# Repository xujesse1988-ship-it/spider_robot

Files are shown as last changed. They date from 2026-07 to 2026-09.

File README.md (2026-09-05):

# Spider · 会爬玻璃的 DIY 六足机器人






<p align="center">
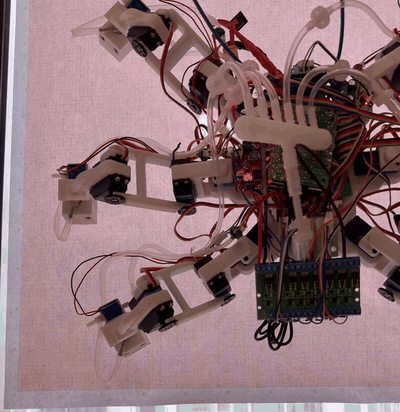
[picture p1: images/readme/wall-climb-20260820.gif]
六足机器人吸在竖直玻璃上原地踏步（2026-08-20）
  
  <br>
  <sub>2026-08-20，竖直玻璃上的原地踏步实验。六只吸盘足，一次抬一条腿，安全绳在画面外。</sub>
</p>

一台 3D 打印的六足机器人：**地上能走，也能吸在竖直玻璃上爬**。18 只几十块钱的舵机、一台隔膜泵、六个十块钱的波纹吸盘，零件总共约两千元。一个 DIY 新手和 AI 结对，从第一次提交到整机上墙用了六周，到现在两个月。

它不是产品，是一张能力证明：用最便宜的零件，把"六条腿上墙"这件事做成了，还顺手发现了一个爬壁机器人的普遍现象并给出了不用传感器的解法（正在写论文）。

> **English summary.** *Spider* is a 3D-printed hexapod that walks on the floor and climbs vertical glass on six suction-cup feet (one normally-closed solenoid valve per foot, one diaphragm pump, no vacuum tank). Brain: Raspberry Pi 5; actuators: 18 × 35 kg·cm hobby servos; parts cost about ¥2,000 (~US$300). Along the way we found that **93% of a climbing step's slip happens in the instant a cup's seal breaks**, and cut three-round slip by **61%** with a sensor-free, purely kinematic "zero-force handover" (paper in preparation, see `docs/PAPER-PLAN.md`). Fully offline voice control. Built in two months by a DIY beginner pairing with an AI coding assistant. MIT licensed; walking platform derived from the open-source [MakeYourPet hexapod](https://github.com/MakeYourPet/hexapod). **Full English translations of every document and report are in [`docs/en/`](docs/en/) and [`html/en/`](html/en/).**

## 它能做什么

| 能力 | 状态 | 说明 |
|---|---|---|
| 竖直玻璃上爬行 | ✅ 2026-08-19 起 | 六足吸盘，每足一只常闭阀，五足支撑一足摆动；不装储气罐，泵直接抽歧管，滞环维持 −60~−75 kPa |
| 停在墙上不掉 | ✅ | 常闭阀断电保持真空，泵间歇工作；掉电不等于掉落 |
| 地面行走 | ✅ | 三角 / 波浪步态，键盘遥控，可调速 |
| 全离线语音 | ✅ 2026-09-02 起 | 喊"小蜘蛛，前进三秒"就走三秒，"停下"立刻停；不联网、不要 API key；声纹锁只听主人，急停谁喊都停 |
| 少往下滑 | ✅ 量化验证 | 零力交接 + 轮转权重：三轮下滑 −61%（n=3，p≈0.001），破裂段 −88% |
| 负重、双墙面、自主上墙 | 🔜 P5 | 见 `docs/ROADMAP.md` |

## 最有意思的一段：每走一步，它都往下滑一点

爬墙跑通之后发现：机器人每换一次脚，整机就往下掉几毫米，三轮下来滑了将近 20 厘米。用手机视频逐帧追踪（NCC 模板匹配 + 阶跃基底分解，188 张核对图入库）之后，答案很干净：

- **93% 的下滑发生在同一个瞬间**：吸盘放气、密封破裂的那一下。
- **原因是腿是软的**：便宜舵机的齿轮系、打印腿、波纹吸盘，整条腿链就是一根弹簧。吸着的时候它承着重力储能，放气瞬间能量一次释放，身体就"弹"下去一格。指令机体位移只有约 42% 被实现，其余都吃进了弹性。
- **解法不用加任何传感器**：放气之前先把这条腿的"力"卸到零。做法纯运动学：给要抬的腿一个离线标定好的位移 δ，其余五条腿按轮转距离加权分摊 −δ，六条腿指令的均值不变，身体不动，腿链里的弹性势能先归还再放气。
- **结果**：三轮下滑 185 mm → 73 mm（−61%），放气破裂段 173 mm → 20 mm（−88%）。这条线正在整理成论文（默认投 RA-L），进度与数字都在 [`docs/PAPER-PLAN.md`](docs/PAPER-PLAN.md)。

想看细节：[`docs/HANDOVER-DESIGN.md`](docs/HANDOVER-DESIGN.md)（设计）、[`html/handover-ab-n3-20260826.html`](html/handover-ab-n3-20260826.html)（n=3 终版报告）、[`html/vent-snap-20260820.html`](html/vent-snap-20260820.html)（现象首次发现）。

## 硬件一览

| 部分 | 用的什么 |
|---|---|
| 步行平台 | [MakeYourPet hexapod](https://github.com/MakeYourPet/hexapod) 3D 打印机身与 coxa/femur（MIT）；小腿换成本项目自制的吸盘一体件 |
| 舵机 | 18 × DS3235 35 kg·cm 数字舵机，¥45~85/只，无任何力矩或位置回读 |
| 舵机板 | Pimoroni Servo2040，跑社区 chica 固件，Pi 经 USB 驱动 |
| 大脑 | Raspberry Pi 5，自研 Python 控制软件 |
| 吸附 | 555 双头隔膜泵 ×1、二位三通常闭电磁阀 ×6、30 mm 2.5 折波纹吸盘 ×6、每足单向阀 + 滤芯、一进六出歧管；无储气罐 |
| 传感 | 六路 XGZP6847A 吸盘压力（ADS1115 读）、母线电压/电流遥测。没有 IMU，没有力传感器，足底开关未启用 |
| 语音 | ReSpeaker Lite USB + 4Ω 3W 喇叭；sherpa-onnx 离线四件套（KWS 唤醒 → Silero VAD → SenseVoice 识别 → Matcha 合成）+ CAM++ 声纹 |
| 供电 | 2S 锂电 7.4 V 直供舵机（继电器切正极）；Pi 独立 5V/5A 降压 |
| 重量 / 成本 | 3.54 kg（2026-09-04 实测，含吸附系统）；零件约 ¥1700~2800，分两批买，见 [`docs/BOM.md`](docs/BOM.md) |

## 软件一览（`software/`）

跑在 Pi 5 上的自研 Python 包，无硬件也能仿真和测试（`--mock`），约 190 项 pytest。

| 模块 | 干什么 |
|---|---|
| `hexapod/kinematics.py` | 单腿 3 自由度正逆运动学 |
| `hexapod/gait.py` | 相位式步态引擎：三角 / 波浪 / 爬墙五足支撑 / 双足摆动 |
| `hexapod/robot.py` | 身体系足端目标 → IK → 18 路脉宽；贴墙姿态偏移 |
| `hexapod/adhesion.py` | 每足吸附状态机（压紧→抽气→吸附→放气）+ 真空回路仿真 |
| `hexapod/driver.py` | Servo2040 chica 串口协议（按固件源码逐字节核实）+ 遥测 |
| `hexapod/voice/` | 唤醒、识别、意图、合成、声纹锁 |
| `scripts/` | `sim_walk` 仿真 → `servo_center` 标定 → `walk_teleop` 键盘走 → `climb_walk` 爬墙 → `voice_teleop` / `voice_climb` 语音 |
| `logs_analysis/` | 手机视频量化管线（`ab_quant.py`）与统计脚本 |

安装、脚本顺序、上电顺序和标定流程见 [`software/README.md`](software/README.md)。

## 两个月时间线

| 日期 | 里程碑 |
|---|---|
| 2026-07-07 | 第一次提交：路线图、BOM、第一批下单 |
| 07-22 | 单腿上墙决策门通过：50 次吸放循环 >95%，挂住 1.5 kg |
| 08-08 | 整机 18 路标定完成，站立实机验证 |
| 08-17 | 每足单向阀装机，一足漏气不再连坐 |
| 08-19 | 整机首次在竖直玻璃上行走（无储气罐） |
| 08-20 | 发现"放气瞬间弹跳下滑"现象；同日实现零力交接 |
| 08-26 | n=3 拉丁方实验：三轮下滑 −61% |
| 08-31 | 论文英文初稿 v0；κ 定律判别实验上墙完成 |
| 09-02 | 语音交互换 ReSpeaker Lite USB，声纹锁上线 |

## 仓库地图

| 目录 | 内容 |
|---|---|
| [`docs/`](docs/) | 路线图、分阶段操作指南、设计论证、论文计划（下表）；英文版在 [`docs/en/`](docs/en/) |
| [`software/`](software/) | Pi 5 控制软件、脚本、测试、视频量化管线 |
| [`hardware/makeyourpet-hexapod/`](hardware/makeyourpet-hexapod/) | 上游步行平台 STL/STEP、接线图（原样收录） |
| [`hardware/climbing-parts/`](hardware/climbing-parts/) | 自制吸盘小腿、门盖、气动舱固定件（[打印说明](hardware/climbing-parts/README.md)） |
| [`tools/`](tools/) | 打印件参数化生成器 |
| [`paper/`](paper/) | 论文 LaTeX 源码（中英）、图、参考文献 |
| [`html/`](html/) | 23 份实验分析与设计图解报告，直接用浏览器打开；英文版在 [`html/en/`](html/en/) |
| [`images/`](images/) | 零件照片、实验视频与 188 张量化核对图 |

### 文档

| 文件 | 内容 |
|---|---|
| [ROADMAP.md](docs/ROADMAP.md) | 分阶段路线图 P0~P5，每阶段验收标准与风险清单 |
| [P0-GUIDE.md](docs/P0-GUIDE.md) · [P1-GUIDE.md](docs/P1-GUIDE.md) · [P2-GUIDE.md](docs/P2-GUIDE.md) | 单腿：下单、打印、装配、真空台架、上墙决策门（含验收数据） |
| [P3-GUIDE.md](docs/P3-GUIDE.md) · [P4-GUIDE.md](docs/P4-GUIDE.md) | 整机：装配、标定、地面行走、气路上机、爬墙步态、启动死机排查 |
| [BOM.md](docs/BOM.md) | 分批采购清单，含淘宝搜索关键词与价格区间 |
| [CLIMBING-DESIGN.md](docs/CLIMBING-DESIGN.md) | 吸附方式选型（为什么不用涵道风扇）、力学预算、气路图、电气架构 |
| [HANDOVER-DESIGN.md](docs/HANDOVER-DESIGN.md) · [HANDOVER-AB-PROTOCOL.md](docs/HANDOVER-AB-PROTOCOL.md) | 零力交接的设计与实机 A/B 实验方案 |
| [DUAL-SWING-DESIGN.md](docs/DUAL-SWING-DESIGN.md) | 双足同时摆动的升级设计 |
| [P4-BAY-DESIGN.md](docs/P4-BAY-DESIGN.md) | 电气与气动舱固定件设计 |
| [VOICE-GUIDE.md](docs/VOICE-GUIDE.md) | 语音交互：硬件接法、离线模型、指令表、抗噪排障 |
| [PAPER-PLAN.md](docs/PAPER-PLAN.md) · [RELATED-WORK.md](docs/RELATED-WORK.md) | 论文总纲、核心数字、文献边界 |
| [weight-log.md](docs/weight-log.md) | 重量记录（爬墙对重量极其敏感） |

## 想自己做一台

开发顺序是按风险排的：**先花几百块用一条腿验证"能上墙"，通过决策门再买整机的舵机**。

1. 读 [`docs/ROADMAP.md`](docs/ROADMAP.md) 的 P0~P2 节。
2. 按 [`docs/BOM.md`](docs/BOM.md) 下第一批单（单腿验证套件，约 ¥600~950）。
3. 等快递时打印一条腿：coxa/femur 用上游 STL（同名多版本取编号最大的），小腿用 `hardware/climbing-parts/left-tibia-suction.stl` + 一件 `suction-foot-door.stl`，装配看上游 YouTube 频道 MakeYourPet。
4. Pi 5 烧 Raspberry Pi OS Lite 64-bit，装 `software/`，先跑 `scripts/sim_walk.py --gif walk.gif` 看步态仿真。
5. 单腿决策门（50 次吸放循环 >95%、撑住 1.5 kg）通过后，再买第二批装整机，按 P3、P4 指南走。

## 安全

- 爬墙测试全程系安全绳、地面铺垫；任何脚本退出都会断舵机电，机器人会趴下，测试时垫高机身。
- 锂电池充电不离人。

## 许可证

本仓库的自研内容（`software/` 控制软件、`docs/` 文档、`tools/` 生成脚本、自制打印件、实验数据与论文源码）以 **MIT 协议**发布，见 [LICENSE](LICENSE)。

第三方内容：

- `hardware/makeyourpet-hexapod/`：MakeYourPet hexapod 原样收录（MIT，Copyright (c) 2022 MakeYourPet.com），许可原文在该目录 `LICENSE`。
- `hardware/climbing-parts/` 中的左右 `tibia-suction*.stl` 派生自上游 `left-tibia.stl`，见 [hardware/climbing-parts/NOTICE.md](hardware/climbing-parts/NOTICE.md)。
- Servo2040 固件 chica（[EddieCarrera/chica-servo2040-simpleDriver](https://github.com/EddieCarrera/chica-servo2040-simpleDriver)，MIT）不包含在本仓库中，`software/hexapod/driver.py` 只实现其串口协议。
- "MakeYourPet" 是上游作者的名称，本项目与其无隶属或背书关系；上游作者的 YouTube 视频等不在 MIT 授权范围内。

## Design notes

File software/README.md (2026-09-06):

# software/ —— 树莓派 5 大脑

Pi 5 通过 USB 连 Servo2040（跑社区 chica 固件），本包实现运动学、步态、驱动协议与吸附控制。
协议已从固件源码逐字节核实（`hexapod/driver.py` 文件头有完整协议说明）。

## 安装

```bash
# 开发机（仿真+测试）
python3 -m venv .venv && .venv/bin/pip install -e ".[sim,dev]"
# 树莓派上（实机）
pip install -e ".[pi]"
```

## 模块

| 文件 | 内容 |
|---|---|
| `hexapod/config.py` | 机器人几何/舵机标定表——默认值全部来自官方 chica-config-2040.txt（连杆 43/80/134mm、通道映射、安装偏角） |
| `hexapod/kinematics.py` | 单腿 3DOF IK/FK（有工作空间检查） |
| `hexapod/gait.py` | 相位式步态引擎：tripod（三角）/ wave（波浪）/ climb（爬墙五足支撑） |
| `hexapod/robot.py` | 身体系足端目标 → 变换 → IK → 18 路脉宽；身体姿态偏移（爬墙贴墙姿态用） |
| `hexapod/driver.py` | Servo2040 chica 协议驱动 + MockDriver；含足底开关/电压/电流读取 |
| `hexapod/adhesion.py` | 吸附状态机（RELEASED→PRESSING→SUCKING→ATTACHED→VENTING）+ 真空回路仿真；`Pi5VacuumIO` 留待 P1 台架按实际接线补全 |
| `hexapod/voice/` | 语音交互（`docs/VOICE-GUIDE.md`）：`intents.py` 识别文本→意图（纯规则）、`keywords.py` 唤醒词→KWS 关键词表、`audio.py` arecord/aplay 录放音、`tts.py` 离线合成+缓存+分句播报、`engine.py` KWS→VAD→SenseVoice 引擎线程、`voiceprint.py` 声纹锁 |

## 脚本（按上手顺序）

```bash
python scripts/sim_walk.py --gif walk.gif        # 0. 无硬件仿真，先看步态对不对
python scripts/servo_center.py                   # 1. 装配标定：全舵机回中，装舵盘
python scripts/stand_up.py                       # 2. 站立测试 + 传感器读数
python scripts/walk_teleop.py                    # 3. 键盘遥控行走 (wasd/qe)；m 键进/出原地踏步（身体不动、手动逐脚：t/g/b=左前中后、y/h/n=右前中后，按一下抬起 70mm 再按踩下，`--march-lift` 改高度；该状态只认这六个键+m+ESC，其余按键忽略；全程六阀通电排气，出踏步时抬着的脚先滑回站位）；装气路后阀策略 --vent auto（默认）：站起/走动时六阀通电排气让吸盘通大气、站着不动断电；on 常通；off 不碰阀=脚被被动真空吸住抬不起（对照，v 键轮换）
python scripts/voice_check.py                    # 4. 语音自检：录 5 秒→回放→识别→TTS（要 ReSpeaker Lite，见 docs/VOICE-GUIDE.md）
python scripts/voice_enroll.py                   # 5. （可选）声纹注册：行走指令只听你，急停谁喊都停；末尾补录"确认/退出"等短词锚点，已有档案用 --append 只补短词
python scripts/voice_teleop.py                   # 6. 语音遥控行走（“小蜘蛛，前进”=一直走喊停为止、“前进三秒”=到点自停、“停下”急停；键盘照旧；阀排气同 walk_teleop）
python scripts/voice_climb.py                    # 7. 爬墙语音壳：climb_walk 原样跑在 pty 里，语音映射成按键注入（急停→空格、“启动”→p、行走→wasdqe、单步/落地→i、“冻结”→f），互锁/黑匣子照旧；退出与取机只认键盘（VOICE-GUIDE §3.9）
```

全部脚本支持 `--mock` 干跑（`voice_*` 还支持 `--wav` 用录音顶替麦克风）。测试：`pytest tests/`（覆盖 IK 往返、步态约束、协议字节、吸附状态机、语音意图/关键词/回声过滤/声纹锁）。

语音一键安装（树莓派）：`bash scripts/voice_setup.sh`，依赖见 `requirements.txt` 语音段。

黑匣子与死机验尸：`climb_walk`/`body_lean`/`walk_teleop`/`voice_teleop` 每跑一次落一份 `logs/<tag>_时间.log`（tag=climb/lean/walk/voice；事件+遥测，`hexapod/runlog.py`）。09-02 起启动段逐步落盘（每路阀线圈通电前、舵机继电器合闸前后母线电压），并由 `hexapod/powerlog.py` 后台线程每 0.1s 记一行 Pi 5 的 5V 输入电压与欠压标志（`TLM 电源`，需 `vcgencmd`，用户在 video 组）。启动死机（灯绿→红、SSH 失联）排查：先 `bash scripts/pi_forensics.sh setup`（内核日志持久化，一次即可）→ 复现 → 重新上电 → `bash scripts/pi_forensics.sh check`；`check` 里的 `power_reset` 两次死机后都是 2，但 09-06 对照发现正常关机后也读 2，本机无区分力，仅作记录；死后红灯常亮本身就是 PMIC 断电的证据。详见 docs/P4-GUIDE.md 常见问题。

## 上电顺序（重要）

1. Pi 5 用独立 5V/5A 降压模块供电，舵机 7.4V 经继电器（Pi GPIO17 控制，08-15 定案，原 Servo2040 A0/GPIO26）供电。
2. 软件流程：先 `set_all_pulses_us` 发好目标脉宽 → 再 `enable(True)`。固件保证舵机使能瞬间直接到设定位，不乱跳。`enable(True)` 内部拆两步：先合继电器（舵机带电不出力）→ 0.4s → 固件使能（同刻出力）；09-03 实机定案启动死机扳机就是合闸瞬间（5V 输入空载仅 4.89V 余量极薄），拆开后峰值分开、黑匣子能分清是哪一记。
3. 任何脚本退出/异常都会 `enable(False)` 断舵机电——机器人会趴下，测试时垫高机身。进程被杀时 lgpio 释放 GPIO17，继电器同样自动断电。

## 标定流程（装配后必做）

1. `servo_center.py` 让全部舵机回中，按官方视频角度装舵盘；
2. 每个关节手动摆到 -45°/+45°，记录脉宽，填入 `config.py` 的 `us_m45/us_p45`；
3. 方向相反的舵机改 `sign=-1`；零位偏差微调 `attach_deg`；
4. 换上吸盘足模块后重新量 `tibia_len`（约 +45mm）。

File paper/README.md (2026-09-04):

# RA-L 论文草稿(T6)

状态:**英文全文初稿 v0(2026-08-31)+ 09-01 读者视角修订**(面向没参与造机器人
的读者:腿命名/术语/隐喻全部落地,图 1 示意图已画,摘要删去"慢放气"跳跃句;
中文版同步)——全部章节成文、核心数字已嵌入,待补图/待办见下。总纲 `docs/PAPER-PLAN.md`;本目录只放论文本身。

## 文件

- `main.tex` — 正文(IEEEtran journal 模式,RA-L 口径;红色 `\TODO{}` 为待办标记)
- `main_zh.tex` / `main_zh.pdf` — **中文对照版**(供内部审阅/交流,非投稿稿;
  与 08-31 英文稿逐节对应,数字/公式/引文/图表一致)。⚠ 投稿以英文为准,
  改英文后中文不自动同步——大改后要么重译要么在中文版头注明滞后。
  编译需 XeTeX+中文字体:本机 Noto Serif/Sans CJK SC 已放 `~/.fonts`
  (仓库不含字体,新机器 fc-list 查无则从 notofonts/noto-cjk 下载);
  Overleaf 上传时选 XeLaTeX 编译器
- `refs.bib` — 45 条引文(源自 `docs/RELATED-WORK.md` 判级表;
  条目内 `TODO(verify)` = 投稿前须人工核全文的字段,总清单在 RELATED-WORK §7)
- `figures/` — 插图(生成脚本与来源见各文件头/下表;`make_fig1.py` 生成图 1
  示意图 (a)(b)(c),纯几何不依赖实验数据;`make_figs.py` 生成图 2–5)
- `references/` — 参考文献 PDF,**文件名=refs.bib 引用键**(现有
  nadan2024loris.pdf=LORIS ICRA 2024,CMU 作者公开版——写作范本兼
  贡献③划界近邻;写作范本首选另见 kim2008smooth=Stickybot T-RO 2008,
  叙事弧同构:同一个敌人"脱附瞬态"、同款"脱开时刻本来就没力"哲学)

## 编译

开发机没装 LaTeX。两条路:

1. **Overleaf(推荐)**:上传 `main.tex` + `refs.bib` + `figures/`,
   编译器选 pdfLaTeX,IEEEtran 类 Overleaf 自带;
2. 本机装 `texlive-publishers`(含 IEEEtran)后:
   `pdflatex main && bibtex main && pdflatex main && pdflatex main`;
3. **本机实际在用的路**:`~/.local/bin/tectonic main.tex`(单命令,自动多遍+bibtex;
   中文版 `tectonic main_zh.tex`,XeTeX 自动选中)。

## 数字溯源(写作时改数必查源)

| 论文位置 | 数字 | 来源 |
|---|---|---|
| 摘要/主表 Table I | −43%/−61%,−82%/−88%,p=0.0013/0.00092/0.0022 | html/handover-ab-n3-20260826.html §1 |
| 头条口径 | 93%(n=3 A 组 vent 段 172.9/185.5);83%=08-20 首次发现口径 | 同上 + html/vent-snap-20260820.html(口径差异=分段窗定义,正文已注) |
| 破裂剖面 | 0.4s 泄压 <0.15mm;33~67ms 完成;正文与图 2b 同一事件:L1 过冲 26.7→21.5(0825/A 重复#1,`ab_quant --zoom`);08-20 首次发现事件为 23.8→21.5(正文不再引用,避免两套数字) | html/vent-snap-20260820.html §4;PAPER-PLAN T3 |
| δ 标定 | 斜率 −0.57~−0.13;δ* 28~42;表 31/33/29/22/22/24;66→50→39mm;δ*/b(0)=1/s 逐腿 **1.7(L1)~8(R2)**(旧稿写 5~8 是等刚度粗算,09-01 已改) | html/handover-delta-calib-20260824.html §3 |
| 传递比 | 42.2±3.0%(9 标记/3 天/3 机位) | n=3 报告发现 2 |
| 模型拟合 | RMSE 0.85/CV 0.99;两路 k̂ r=0.938;B 60.2=6.7+55.5;C 39.7=7.7+30.0 | html/stiffness-fit-20260826.html |
| κ 定律 | Δb=κ·δ(1+0.20(r−1));κ_B 0.0988/κ_C 0.0550/κ_31 0.0529;权重压 44% | html/dprime-20260831.html(M10 AICc 0.0 vs M8 17.8;216 点) |
| D′ 配对 | D′−C 交接段 −2.9±2.1(p=0.14);总 −1.7±0.7;落点比例 0.21;合并段 −3.0±3.1 | 同上 §1-2 |
| vent 窗定义 | 起点=A 组阀开前 1s / B、C 组阀开时刻(交接段终点);终点=released 事件(盘压回到 ≥−5kPa,俗称"盘压归零")后 +0.4s;两端锚不同事件、非"归零 ±" | software/logs_analysis/ab_quant.py:575-595(09-01 已核,论文已按此改写) |
| 联合 k̂ | L1 0.265/R1 0.227/L3 0.137/R2 0.133/R3 0.125/L2 0.112;γ=0.11 | 同上 §3 |
| 系统参数 | 吸附 ≤−30kPa 持续 0.2s;泵滞环 −60/−75(**作用于最浅已吸附盘压**,任一盘抽气中泵常开);抬腿门槛 −50kPa;**全部 15 组实验 --no-tank、单泵直抽歧管**(储气罐从未装机);连杆 43/**81**/123.7;抬腿=名义面上 15mm(指令行程 33=press 18+15) | software/hexapod/adhesion.py, config.py, body_lean.py,日志 argv(09-01 已核) |

## 待办(投稿前;`main.tex` 内红字与此同步)

1. **作者/单位/邮箱/资助**(main.tex 头部)。
2. ~~**整机称重**~~ ✅ 09-04 实测 3537g:Sec III-A 中英已改 $3.54$ kg、\TODO 已删;讨论段 "sub-3 kg climbers" 随之改 "few-kilogram climbers"(中文"几公斤级"),因为本机已不在 3kg 以下。
3. **图**:Fig.1 示意图 (a)(b)(c) 已由 `make_fig1.py` 生成,**真机照片 (d) 待拍**;Fig.2 阶梯轨迹+破裂剖面
   (T3,`ab_quant --zoom`);Fig.3 弹跳-δ 线性;Fig.4 分解瀑布+逐腿弹跳;
   Fig.5 D′ 对齐剖面。figures/ 里已生成的见文件头注释,其余 `\TODO`。
4. ~~vent 窗定义核对~~ 09-01 已从 ab_quant 源码确认并改写(见溯源表)。
5. **T4a 挂重**(绝对 k+蠕变率直测)与 **T4b 净前进率 demo**(26%→X%)
   结果出来后并入 Sec VII(讨论已留钩子);26% 基线数字当前来自 08-19。
6. **投稿视频**:A vs C 并排 + 破裂慢放(MOV 原片冻结在本机,协议见 PAPER-PLAN T6)。
7. **开源数据包**:日志/traj/report/188 张核对图/管线脚本打包,定托管处与许可证。
8. **refs.bib 逐条核全文**(`TODO(verify)` 字段 + RELATED-WORK §7 清单:
   Kumar&Waldron 1990 措辞、FTFOF 开/闭环细节、Ota 2006 正文、CNKI 硕博)。
9. **篇幅**:RA-L 8 页含引文;当前英文稿 10 页(09-01 加图 1 + 术语解释后从 9 页涨到 10),定稿时砍
   (候选:Related Work 六段压四段、P1-P4 合并表述、偏差清单压缩)。
10. 术语统一自查:vent-snap ratchet / zero-force handover / handover segment /
    rupture segment / transfer ratio / per-mm transfer loss(κ)。
    09-01 已统一:"laid/laying"→transfer(ed);"up/down-slope"→up/down the wall;
    "winding"→loading;"gait engine"→gait controller;M10/M8→H2/H1;
    定义处:leg names(III-A)、round/rotation(III-C)、body lean(III-B)、
    discovery run(I)、rupture-segment slip(III-B)、leak-rescue(V-D)。
11. **靶标交叉验证跑 + 核对图整理(09-01 新增,详见 PAPER-PLAN T4d)**:
    贴 Ø20 同心圆靶标(`html/tracking-targets-printable.html`)跑一组原地
    基线,同一视频板模板 vs 靶标两种追踪比对,III-B 改写为"两种追踪一致到
    X mm";此后所有上墙视频一律贴靶标。**不重做 n=3/D′**(理由见 T4d)。
    在此之前:III-B 那句"人工对 188 张核对图核查"要改为不带张数、不称
    人工(操作者确认过的只有皮尺 4 帧);`images/ab-verify-202608/` 只有
    board_scale×9 + locate×15 + 皮尺 12 张是自解释核对图,开源包只放这
    36 张 + 索引 README,其余 ~150 张读角过程图挪子目录。

## 09-01 事实核查修正清单(改回去就是错的,动这些句子前先看源)

三路核查(代码/日志、n=3+标定报告、拟合+D′ 报告)对全文事实句逐条比对后改掉的口径:
- 传感器:机器人**有**六路吸盘压力传感器+母线电压/电流遥测(无 IMU、足底开关未接、舵机无回读)。
  只能写"交接不用任何传感反馈/不新增传感/无力传感",不能写"零传感器/no pressure feedback"。
- 气路:无储气罐、单泵直抽歧管;阀断电=吸盘↔歧管(失电安全),通电=通大气;单向阀在歧管—阀之间。
- 协议:n=3 九组**没有**内建 60s 静置(人工 21~58s;60s 内建 08-26 才加,只对 D′ 六组有效);
  腿间节拍=≥10s 且泵停 ≥2s,实际全由 10s 下限决定;首场电压 7.88V(非 ≥7.9);
  机位在 #1 A→B(~128px)、#2 C→A(数十 px)组间动过,"场内未动"是错的;组内漂移 ≤4.8px。
- 现象:软腿 vent 弹跳 L2 3.5/R2 6.1(5.8/5.9 是全周期列,HANDOVER-DESIGN §1 混列);脚回弹 9~15 为下限;
  静置段 2.4~4.7mm/组(不是"零");"131 vs 131.3"是分段和核对,其比例本就由该读数标定,不是独立验证。
- 模型:e/b=(K−k)/k 逐腿 1.7~8(非 5~8);"弹跳 21mm 饱和低于线性预测"是 08-20 推测且被 24~28 实测推翻,
  改为"硬腿 20~27 平台+模型高估前进损失 ⇒ 归因扭矩饱和(假说)";P2 首抬 n=3 基线 2.5~4.3 非 ≈0;
  P3 4.6 用的是斜率 k̂、RMSE 0.85 是 54 单元含共模项;P4 "全给一条 0%/非单调"不可复现已删,+30% 是温和档反向;
  B→C 跨指标 −30~−36%(非 −31~−33)。
- 方法:首轮指令伪迹按部署表仿真 ≈14mm(B)/20mm(C)(旧 ≤5mm 来自旧表);δ 表**未**在权重下重标,B/C 同一张表;
  "首版表 74→50"无此实验已删;代码 ≈150 行(含注释 270)。
- 结果:R1 上弹实测两次 ≈−0.9mm(B 组),−1~−3 是协议预期值;交接段占比 B 56~58%/C 47~62%;
  R1 交接段不逐轮增长;其余四腿 0~2mm;传递比"2 天 3 场 5 机位";相对效应重复间差 ≤5 点(非 3)。
- 拟合/D′:k̂ 与 c0 退化,只报排序/比值可靠(c0=1.15);共模占比 B 92%/C 76~84%(非"九成");
  L1 残余系数按自报 k̂ 为 0.038≈1.4mm/次(0.019 是旧拟合);观测数据上 H1/H2 不可分(ΔAICc≈2 略偏 H2),
  "H1 险胜"是错的;D′−C 差"主要是窗口归因"只对 1/3 配对成立;偏差(vi)是 D′ 两组、挪 4~5mm/组。
- 上游文档 docs/HANDOVER-DESIGN.md §1/§5 仍留着"5~8 倍""L2 5.8"等旧口径,引用前以本表为准。
- 语气:09-01 按用户要求去修辞化(中英同步)——删掉"纳税/这笔税""住进指令流""下一个要拉的杠杆""头条""教科书式""互相较劲""明码标价""翻案""白捡""最凶""口味""恰恰…最付不起"等隐喻和戏剧化强调,讨论节两个反问式小标题改为陈述式;写新句子沿用平实学术表述,不要再往回加。

## 措辞红线(T5 定界,动 Related Work/贡献段前必读)

- ❌ 不写"首次提出脱附前卸载"(Stickybot 专利 US7762362B2 + LORIS Unload 步在先);
  ✅ 只主张:位移域换算 + 零传感器纯开环 + 破裂段滑移量化验证。
- FTFOF 的 −82% 是振动(m/s²),与我们 −82%(mm)量纲不同——正文已点破,勿删。
- 发现 2(42% 传递比)写"平台特性表征",不写"新物理"。
- 所有"首次"均带 "to the best of our knowledge"(CNKI 墙内是唯一未彻底排除的暗区)。

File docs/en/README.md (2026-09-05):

# English versions of the project documents

Every file here is a full English translation of the same-named file in [`docs/`](../). The Chinese originals are the maintained source; if the two differ, the Chinese version wins. Links between documents stay inside this directory; references to HTML reports point to their English versions in [`html/en/`](../../html/en/). The data files (`docs/data/`) are shared and not duplicated.

| Document | What it covers |
|---|---|
| [ROADMAP.md](ROADMAP.md) | Staged roadmap P0–P5 with acceptance criteria and risk list per stage |
| [P0-GUIDE.md](P0-GUIDE.md) · [P1-GUIDE.md](P1-GUIDE.md) · [P2-GUIDE.md](P2-GUIDE.md) | Single leg: ordering, printing, assembly, vacuum test rig, the wall decision gate (with acceptance data) |
| [P3-GUIDE.md](P3-GUIDE.md) · [P4-GUIDE.md](P4-GUIDE.md) | Whole robot: assembly, calibration, floor walking, pneumatics on the robot, climbing gait, startup-crash troubleshooting |
| [BOM.md](BOM.md) | Purchase list in batches, with Taobao search keywords and price ranges |
| [CLIMBING-DESIGN.md](CLIMBING-DESIGN.md) | Adhesion method selection (why not ducted fans), force budget, pneumatic circuit, electrical architecture |
| [HANDOVER-DESIGN.md](HANDOVER-DESIGN.md) · [HANDOVER-AB-PROTOCOL.md](HANDOVER-AB-PROTOCOL.md) | Design of the zero-force handover and the real-machine A/B experiment protocol |
| [DUAL-SWING-DESIGN.md](DUAL-SWING-DESIGN.md) | Upgrade design for swinging two legs at once |
| [P4-BAY-DESIGN.md](P4-BAY-DESIGN.md) | Mounting parts for the electrical and pneumatic bay |
| [VOICE-GUIDE.md](VOICE-GUIDE.md) | Voice interaction: hardware, offline models, command table, noise troubleshooting |
| [PAPER-PLAN.md](PAPER-PLAN.md) · [RELATED-WORK.md](RELATED-WORK.md) | Paper master plan, core numbers, literature boundary |
| [LEG-GEOMETRY-OPEN.md](LEG-GEOMETRY-OPEN.md) · [L3-DISPUTE-OPEN.md](L3-DISPUTE-OPEN.md) | Leg-geometry investigation record and the resolved tibia-length dispute |
| [weight-log.md](weight-log.md) | Weight log (climbing is extremely sensitive to weight) |

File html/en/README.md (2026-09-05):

# English versions of the HTML reports

Every file here is a full English translation of the same-named file in [`html/`](../). The Chinese originals are the maintained source; if the two differ, the Chinese version wins. Each page is self-contained (only Google Fonts are loaded from the network) and opens directly in a browser.

## Experiment reports (in date order)

| File | What it is |
|---|---|
| [press-lurch-20260819.html](press-lurch-20260819.html) | First real climb on the glass door: why a leg gets "dragged down" before lifting (press reaction bending the leg chains, not cup slip) |
| [vent-snap-20260820.html](vent-snap-20260820.html) | Stepping-in-place experiment quantified: 83% of the slip happens at the instant the vented seal ruptures; the vent-snap ratchet and the zero-force handover idea |
| [handover-delta-calib-20260824.html](handover-delta-calib-20260824.html) | δ calibration in three runs (δ = 0/12/24): bounce is linear in δ, extrapolated δ* = 28–42 mm per leg; bounce ≠ stored energy |
| [handover-ab-20260825.html](handover-ab-20260825.html) | Three-run A/B/C on the wall (baseline / handover / handover + weights): −42% and −61% three-round slip, replicate #1 |
| [handover-ab-n3-20260826.html](handover-ab-n3-20260826.html) | n=3 Latin-square main results: −43% / −61% total slip, −82% / −88% at the rupture instant, paired tests, deviation log |
| [stiffness-fit-20260826.html](stiffness-fit-20260826.html) | Parallel-spring model fit of the handover segment: ~90% of the residual is common-mode sinking, not stiffness inequality; gate decision on the stiffness-aware share |
| [dprime-20260831.html](dprime-20260831.html) | D′ discrimination experiment: handover-segment sinking is proportional to the amount apportioned, not to time (the κ law); weights cut κ by 44% |
| [pi-crash-ground-loop-20260904.html](pi-crash-ground-loop-20260904.html) | Case file: Raspberry Pi 5 dying at servo-relay closure, traced to a charging pulse entering through the USB ground loop |

## Design drawings and wiring (P2–P4)

| File | What it is |
|---|---|
| [fkp-glass-poses.html](fkp-glass-poses.html) | P2: the FKP leg triangle relative to the glass in the lift-off and press poses |
| [p2-rig-diagram.html](p2-rig-diagram.html) | P2: single-leg wall test rig geometry (side view, to scale) |
| [coxa-pedestal-mount.html](coxa-pedestal-mount.html) | P2: printed coxa pedestal / one-piece carriage for the rig, with the 2026-07-19 measured corrections |
| [theta-measure-diagram.html](theta-measure-diagram.html) | Single-leg calibration: which angle θ / α / γ is and how to measure it |
| [tibia-three-view.html](tibia-three-view.html) | Tibia printed part in three views: knee axis = servo output shaft, l3 = 123.7 mm (dispute closed) |
| [p4-system-diagram.html](p4-system-diagram.html) | P4: whole-robot electrical + pneumatic connection topology, relay wiring, valve state semantics |
| [p4-pi-wiring.html](p4-pi-wiring.html) | P4: Pi 5 pin-level wiring (40-pin header, USB, power routes) |
| [p4-divider-board.html](p4-divider-board.html) | P4: 7-channel divider board build drawings (schematic, perfboard layout, checklist) |
| [p4-pneumatic-electrical.html](p4-pneumatic-electrical.html) | P4: terminal-level wiring of the pneumatic subsystem (dual 12 V rails, MOSFET board, grounds, current budget) |
| [p4-bay-v1-assembly.html](p4-bay-v1-assembly.html) | P4: interactive 3D assembly view of the V1 equipment bay and whole robot |
| [tracking-targets-printable.html](tracking-targets-printable.html) | A4 print page of vision tracking targets (1:1) for the video pipeline |

## Explainers

| File | What it is |
|---|---|
| [gait-to-servo.html](gait-to-servo.html) | From a walk command to 18 servos: the full climb_walk chain (phase clock, IK, calibration, serial packet) |
| [servo-primer-20260821.html](servo-primer-20260821.html) | Servo primer: what is inside, how it reads an angle, how it misbehaves under load, what to buy |
| [knowledge-map-20260821.html](knowledge-map-20260821.html) | Knowledge map: the thirteen areas this project needed, what to learn first, six lessons not in the books |
| [dev-timeline-20260821.html](dev-timeline-20260821.html) | Development timeline 2026-07-21 to 08-21, compiled from the chat sessions |

The English pages were produced by extracting every Chinese text segment from the original (text nodes, attributes, JavaScript strings, source comments) and injecting translations back without touching markup, CSS, SVG geometry or embedded images. Some SVG labels are longer in English than in Chinese and may sit closer to neighboring elements than in the original.

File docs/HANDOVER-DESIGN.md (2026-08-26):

# vent 前零力交接（zero-force handover）· 实现设计

状态：**已实现**（2026-08-20 定稿并同日实现：`hexapod/climb.py` update() 4.7 步
+ `LegConfig.handover_mm` + 两脚本 `--handover`；测试 §7 全部 8 项 + mock 冒烟
通过。实现时的设计外补充：`scripts/sim_walk.py` 的 CLIMB_COLOR 也按相位取色，
已补 HANDOVER 键——与 §3.2 PHASE_CH 同族的 KeyError 隐患，设计漏列。
**待办：§9.3 实机 A/B 验收**——实验方案与量化工具已备好：
`docs/HANDOVER-AB-PROTOCOL.md` + `software/logs_analysis/ab_quant.py`）。
2026-08-24 多摆泛化（docs/DUAL-SWING-DESIGN.md，双足爬行）：`_ho_left`
改按腿存（两交接可重叠）、分摊改每 tick 按当前 STANCE 集合现算（单足工况
与旧定格逐位一致；权重表仍在放行时定格）、δ=0 也统一先进 HANDOVER（同拍
直落 VENT，拍间不可观测）、放气加"窗头序队列+VENT_STAGGER_S 错峰+门槛
复检"三关——本文 §3.4/§3.5 的"一次一腿、不需要按腿存"描述仅存档，现行
实现见 climb.py 4.7 步。同日 v1.1：权重（§5 v1.5）双足解禁——单足实测
权重对下滑改善明显后，份额改"按轮转距离取值+当前支撑集就地归一"
（_share_now，每 tick 现算；单足恒 5 支撑=与定格表逐位一致），档位按
口径分家：双足推荐 1,1,1,0,0、单足激进档勿照搬（DUAL-SWING-DESIGN
§3.5/附录 C 模型）。
实测依据：`html/vent-snap-20260820.html`（08-20 原地踏步实验量化报告）、
`software/logs_analysis/lean_20260820_102117.log`、`images/lean_20260820.mp4`。

---

## 1. 要解决的问题（一段话）

零指令原地逐腿抬落，机器人每轮沿墙下滑 57→74mm；逐帧量化显示 **83% 的下滑
发生在放气密封破裂的一瞬间**（阀开后 0.4s 泄压期身体位移 <0.15mm，破裂后
<100ms 内一步坠到位，带过冲振铃）——被抬腿自吸附以来储存的弹性势能
（身体每下沉 1mm，该腿被绕紧 1mm）在脱吸瞬间释放，身体坠到其余五腿的新增
变形接住为止，随后被下一次吸附锁死成棘轮。press 落地只占 4%（vent-first
时序下 press-lurch 已退居次要）。整机电流 0.73→~1.9A 逐周期爬升不回落，
是腿间内应力累积的电学证据。**慢放气已被数据否决**：力的释放不随泄压渐进，
全部压缩在唇口脱开一瞬——治法只能是让脱开时刻这条腿本来就不带力。

单次弹跳按腿（第二轮，mm）：L1 20.9 / R1 19.2 / L3 13.5 / R3 11.8 /
R2 5.9 / L2 5.8。前腿（上方腿，剥离力矩集中）最大。单腿弹跳封顶 ~21mm
（舵机扭矩饱和限制单腿储能），这解释了爬行仍能净前进 26% 而非倒退。

## 2. 原理

**吸住的脚不能滑 ⇒ 改指令 = 改力，不改位。** 这是整个方案的物理基础，与
现有 VENT 段"贴面随支撑场平移"完全同一性质（引擎已有先例，update() 第 4 步）。

一维弹簧账（每腿一根弹簧 k，y_i = 锚点 − 指令 = 该腿"暗示"的身体位置，
X = mean(y_attached) − mg/(n·k)）：抬腿 j 无跳变的充要条件是 **f_j = 0**，
即 y_j = mean(其余) − mg/5k。做法：**把被抬腿的足端指令沿"上坡"方向还 δ
（卸载自己），同时其余五条支撑腿的指令各沿"下坡"方向多走 δ/5（接住载荷）**
——六腿 y 的均值不变 ⇒ 身体纹丝不动；y_j 单独降 δ ⇒ f_j 清零。随后放气，
密封破裂时无能量可释放。1-D 模型验证（附录 A）：基线净前进 25.8%（与实测
26% 咬合）→ 零力交接后 100%；原地踏步 −35.6mm/周期 → 0。

三个工程性质：

- **其余腿承担的力不超过抬腿后本来就要承担的量**——交接只是把载荷移交提前、
  并做成无损，没有新的最坏工况；
- 指令几何自洽有界：某腿在一个周期里作为支撑腿吃 5 次 δ/5（共 −δ 下坡），
  轮到自己抬时先 +δ 卸载正好抵回站位附近，落点又是站位——指令不发散，
  单腿最大额外外摆 ≈ δ（工作空间账见 §4.7）；
  ⚠ **"均值不变 ⇒ 身体纹丝不动"在逐腿 δ 表下只近似成立**（审核实测）：
  落地把被抬腿放回默认站位=丢弃其累计交接偏移，"正好抵回"只在均匀表下
  精确。逐腿表（L1 17…L2 5）下，一条腿支撑期吃进 ≈ mean(其余 δ)、轮到
  自己归还的却是 δ_i，残差在落地瞬间被复位吞掉——六腿指令均值每次落地
  跳一步（L1 落地 ≈8mm 上坡、L2 ≈6.4mm 下坡）。真机引擎按协议抬腿序
  实测：首轮累计 ~4.8mm 上坡指令伪迹（行走时峰值 10.7mm）、轮内 ±1.3mm
  摆动（均匀表 0.53mm）；**稳态每轮漂移仍为 0**。判读纪律见 A/B 协议
  §1 判据 4 注与 §6 首轮分支；
- 方向沿 `_down`（下坡方向，随积分航向旋转，与 sag_comp 同一套）：本实验
  横向漂移仅 7.6mm/131mm，纵向单轴假设成立。

## 3. 机构设计

### 3.1 配置

- `LegConfig.handover_mm: float = 0.0`——逐腿交接量 δ（0=关，默认关；与
  `press_delta_mm` 同为逐腿字段）。放 LegConfig 而不是 RobotConfig：实测
  逐腿差 4 倍（L1 17 vs R2 5），全局一个值没法用。
- `RobotConfig.handover_rate_mms: float = 10.0`——交接铺设速率（08-26 起
  参数化，单源在 config；`climb.HANDOVER_SPEED_MMS` 降级为默认别名供测试/
  文案时长账）。默认 10 与 LEAN_SPEED_MMS 同量级（吸住的脚改指令要慢，给
  载荷重分配留准静态时间），δ=17 时交接段 ~1.7s、δ 表 22~33 时 ~2.7-3.8s。
  引擎 `__init__` 守卫 0<rate≤50(nan/inf 拒)——CLI 之外直设 config 的路径
  也拦(与权重同教训)。**D′ 判别实验=20**:T1 拟合(html/stiffness-fit-
  20260826.html)发现交接段 ~九成是"共模下沉≈蠕变率×窗时长",而窗时长
  ≈0.5+δ/rate 与 δ 完全共线,提速是"时间蠕变 vs 逐 mm 损耗"的唯一离线
  判别(协议 §9)。

### 3.2 新相位

`LegPhase.HANDOVER = "handover"`，插在窗头决策与 VENT 之间：

```
STANCE →(窗头决策放行)→ HANDOVER →(δ 铺完, request_release)→ VENT → LIFT → …
```

⚠ `runlog.PHASE_CH` 必须加 `"handover": "Z"`（零力）——status_line 和
ClimbWatch 遥测都查这张表，漏加 = KeyError 炸主环/黑匣子。ClimbWatch 的
相位跳变日志（`相位 X stance→handover`）走 `.value` 通用路径，自动生效。

### 3.3 窗头决策改动（update() 第 2 步 else 分支）

现有该分支做的事**全部保留原位**：`landing` 计算、轮次推进（step_leg）、
`_swung_since_go` 记账、sag_comp 装填、`step_pending→step_active`、
`_slot_active = True`。唯一改动是收尾动作分叉：

```python
if self.cfg.leg(cur).handover_mm > 0.0:
    self._ho_left = self.cfg.leg(cur).handover_mm
    self.phase_of[cur] = LegPhase.HANDOVER      # 先交接，不放气
else:
    self.ctl.request_release(LEG_NAMES.index(cur))
    self.phase_of[cur] = LegPhase.VENT          # 现行为，一字不动
```

`request_release` **推迟到交接完成**才调用——交接期间吸盘必须保持密封吸附
（ATTACHED 控制环照跑，互锁/漏气监护对它照常成立）。

### 3.4 交接运动（update() 新 4.7 步，紧跟 4.6 倾身之后）

与 4.5（下滑补偿）/4.6（倾身）同一类"直接改足端目标"的全局步：

```python
# 4.7 零力交接：被抬腿沿上坡还 δ（卸载），其余支撑腿各沿下坡 δ/n（接载），
# 均值不变=身体指令不动；按真实时间匀速铺（载荷重分配是准静态过程），
# 漏气挽救期暂停（漏着的盘摩擦余量低，不该被推）。铺完才放气进 VENT。
if (not leak_pause and self._slot_active and self._slot_leg is not None
        and self.phase_of[self._slot_leg] == LegPhase.HANDOVER):
    cur = self._slot_leg
    step = min(self._ho_left, HANDOVER_SPEED_MMS * dt)
    self._ho_left -= step
    dx, dy = self._down
    sup = [n for n in LEG_NAMES if self.phase_of[n] == LegPhase.STANCE]
    self.foot[cur][0] -= dx * step          # 反下坡 = 上坡 = 卸载方向
    self.foot[cur][1] -= dy * step
    for n in sup:                           # 用实际支撑数而不是写死 5
        self.foot[n][0] += dx * step / len(sup)
        self.foot[n][1] += dy * step / len(sup)
    if self._ho_left <= _EPS:
        self.ctl.request_release(LEG_NAMES.index(cur))
        self.phase_of[cur] = LegPhase.VENT
```

`_step_swing` 加一个 `elif ph == LegPhase.HANDOVER: pass` 分支（运动在 4.7
驱动；`_seg_t` 照常计时备诊断）。不需要独立超时监护：速率固定必然铺完，
唯一能拖住它的是 leak_pause，而漏气自己有 `leak_rescue_s` 冻结兜底。

### 3.5 引擎新状态

`__init__` 加 `self._ho_left = 0.0`。一次一腿的窗序保证同时至多一个交接
在途，不需要按腿存。

## 4. 与现有机制的相互作用（逐条，全是坑）

1. **⚠ 支撑场跟随（最大的坑）**：update() 第 4 步现在只让
   `(STANCE, VENT)` 的脚随支撑场平移并保持压入深度。HANDOVER 期间脚仍然
   吸在墙上，行走模式下身体在动，**必须一并跟随**，否则该脚在墙面系被拖着
   划、蹭移还密封着的唇口。改为 `(STANCE, VENT, HANDOVER)`，z 保持
   压入深度的那行同样覆盖 HANDOVER。交接位移（4.7）叠加在场平移之上，
   与 sag_comp 叠加口径相同。
2. **相位钟**：HANDOVER 非 STANCE，第 3 步走 `adv = min(dt, 窗剩余)` 分支
   ——爬行模式窗头 0.6s 用不完 1.7s 交接，钟停在窗尾等它，周期自然拉宽
   （与现有"钟停等吸附事件"同语义，不需要新代码）。原地抬起（零速）钟本来
   就空转，无影响。
3. **sag_comp（4.5）**：注入条件是 slot 腿在 LIFT/TRANSFER，交接期间不注入,
   天然互斥。**交接生效后建议把 sag_comp 归零停用**——它是"坠后追补"的
   治标层，两者同开会双份推挤支撑系白吃工作空间（A/B 期间只开一个）。
4. **倾身（4.6）**：lean 只在全腿 STANCE/HOVER 时推进，HANDOVER 自动把它
   暂停——不改代码，行为正确（交接期间不该再叠加整体平移）。
5. **漏气**：4.7 有 `not leak_pause` 门——交接暂停不丢，与 4.5/4.6 同禁区;
   挽救超时走现有冻结。
6. **冻结/解冻**：frozen 时 update() 顶部早退，交接自动保持（目标全冻）。
   `clear_freeze()` **不取消**在途交接（与"摆动中的 step_active 保留"同
   口径：这条腿已经过了窗头决策必须走完收口；且交接是慢速可逆动作，恢复
   续铺无害）。注意与"未铺完倾身取消"的差别：倾身是纯人工请求可弃，交接
   是抬腿动作的一部分。
7. **工作空间账**：支撑腿因交接的最大额外下坡外摆 ≈ δ（一个周期内攒 5 次
   δ/5，轮到自己抬时才抵回）。
   - body_lean 原地实验（零速、站位、stand 62）：余量 ≥80mm，δ≤20 随便放,
     不加码。
   - climb_walk 行走：δ 要进支撑尾总账（现账 = 半步幅 + 5×sag_comp + VENT
     随场拖尾，见 `comp_tail`）。v1 先文档声明"大步幅 + 大 δ 不同开"，
     启动打印把 δ_max 与 `comp_tail − 半步幅` 并排亮出来；把 δ 计进
     `max_straight_step` 与 sag_comp 动态限额的公式留到交接在实验里站住后
     再做（避免为还没标定的参数改总账公式）。
   - 被抬腿自己的 +δ 上坡方向是它即将摆去的方向，不吃账。
8. **互锁/门槛**：窗头决策已检查过（其余 5 足 ATTACHED 且盘压深于
   lift_gate_kpa）才进 HANDOVER；交接 ≤2s 内若支撑腿翻脸走漏气路径（见 5）。
   交接完成时不重查互锁——与现行"VENT 起不再重查"同口径。
9. **request_lift / 单步 / 连续行走**：三条路都走同一个窗头决策，交接
   自动全覆盖；`air_mode` 吸不上照走交接（无害，多花时间），不加旁路。
10. **启动序列 / RETRY_LIFT**：启动逐足压入无抬腿，重试回抬时吸盘本来就是
    FAULT 未吸附——都无储能可释放，不经过 HANDOVER（代码路径天然不经过，
    确认即可）。
11. **遥测**：`PHASE_CH` 加 `"handover": "Z"`（§3.2）；黑匣子相位跳变自动
    记录。可选：TLM tag 里加剩余交接量（`交余=X.X`），实现时看着办。

## 5. δ 标定

⚠ **2026-08-24 标定语义更正（三组原地 A/B 实测，下表仅存档勿再用）**：
δ=0/12/24 三组（`lean_20260824_13*`，量化管线+阶跃对时）显示逐腿弹跳对
δ 严格线性，外推零弹跳需 **δ*≈28~42mm/腿**（L1 39 / R1 41 / L3 37 /
R3 28 / R2 28 / L2 30，第 2 轮拟合，比例无关口径；斜率 −0.57~−0.13 逐腿
差 4 倍=腿链刚度差）。下表"弹跳×0.8"起标法错把放气瞬间的弹跳当储能——
弹跳是储能被其余五腿并联接住后的读数（≈储能/5~8），系统性低 4~8 倍，
δ=24 顶着旧上限仍全体下弹（每轮下滑 66→50→39mm）正是这笔账。新标定法：
**跑 δ=0/半/全三组线性外推，取 δ*×0.8 起标**，解析上限随之 25→45（§6）。

起标值 = 08-20 实测单次弹跳 ×0.8（宁欠勿过纪律，与 sag_comp 同）：

| 腿 | L1 | R1 | L3 | R3 | R2 | L2 |
|----|----|----|----|----|----|----|
| 实测弹跳 mm | 20.9 | 19.2 | 13.5 | 11.8 | 5.9 | 5.8 |
| **δ 起标 mm** | **17** | **15** | **11** | **9** | **5** | **5** |

- 这组数是**原地踏步、stand 62、trim 6** 工况的稳态值；行走模式支撑场
  持续绕紧，前腿真实储能可能更大——先用 body_lean 原地 A/B 标定，
  再上 climb_walk 单步（i 键）微调，最后连续行走。
- 过冲的代价：δ 超过真实储能会把被抬腿反向预载（释放时身体向上弹一下）
  ——小过冲无害甚至顺向，大过冲白吃工作空间 + 反向蹬一脚，×0.8 起步逐次加。
- v2 方向（本期不做）：交接过程中盯整机电流（实验显示 0.73→1.9A 的信号
  量级足够，0.5s 采样可用）——电流降到平台 ≈ 卸载到位，可做成自适应 δ。
- **v1.5（已实现，默认关）：载荷分配按窗序轮转距离加权** `--handover-weights`
  （5 权重：w1=最晚才轮到抬的支撑腿=刚抬过的，w5=下一个要抬的；不带值=
  激进档 0.6/0.25/0.1/0.05/0）。附录 A 模型数值：均分下稳态每次抬腿储能
  29.7，晚轮到多接·温和 24.1（−19%）、激进 20.2（−32%）、全给一条 29.7
  （收益归零，**非单调**）、反向 38.7（+30% 更糟）。机理：每次落地的零预载
  锁定把受力格局重摊——早收到的载荷被后续落地稀释回集体，晚收到的原封不动
  攒到该腿自己抬腿，稀释机会最多的腿多接。任意归一化权重下均值不变（身体
  指令不动）与每轮零下滑照旧成立（数值验证）。⚠ 排序按窗序距离不按"落地
  新旧"——从第一抬就正确、不依赖吸附历史（历史教训：第一版按落地新旧排，
  当时启动吸附序还是 L1..R3 ≠ 窗序，首轮分错腿被用户提醒抓获后返工；启动
  吸附序后来也改成了窗序 R3→L1→R2→L3→R1→L2，落地新旧与轮转从启动起对齐，
  但排序独立于吸附序这一点保持）；代价=口径假设按轮转抬腿。
  **轮转口径守卫（v1.6 审核加固）**：偏离轮转（反复抬同一腿标定 δ 等）时
  照套权重会把 w1 份额每次砸向同一条支撑腿且永不归还（落地复位只清被抬腿
  自己）——激进档 0.6δ/次实测 4~6 次吹爆工作空间；引擎在交接启动时检查
  "本抬腿 = 上一抬腿的窗序继任者"，不是则该次退回均分 δ/5 并 handover_note
  留痕（脚本亮出）。⚠ 开权重改变稳态运行点，δ 表需下调重标（预期
  −20~30%）；与 δ 标定分开做 A/B。

## 6. 脚本接口

两个脚本都加 `--handover` 参数，格式二选一：

- `--handover 8`：六腿统一 δ=8；
- `--handover L1:17,R1:15,L3:11,R3:9,R2:5,L2:5`：逐腿设（可只给部分腿，
  未给的保持 0）。

解析后 `replace(leg, handover_mm=…)` 进 cfg（照抄 `--press-delta` 的
replace 模式）。范围校验 0~45mm（2026-08-24 起：三组外推 δ*≈28~42 加余量；
旧上限 25 的"弹跳封顶 21 ⇒ 更大没意义"是弹跳当储能的错账，见 §5 ⚠——
工作空间由 climb_walk 启动硬拒与 4.7 步逐 tick 截断另守）。启动打印每腿 δ 与
交接段时长。body_lean 文档头/键位说明补一句"抬起前自动先做零力交接
（--handover 开启时）"。climb_walk 同步。
两个脚本另有 `--handover-rate`（08-26 起）：铺设速率 mm/s，默认 10=n=3
基线口径，须同开 `--handover`；CLI 校验 0<r≤50 + 引擎再验，铺设速率写进
日志参数行（`handover_rate=`）供量化溯源。D′ 判别实验=20（协议 §9）。

## 7. 测试清单（tests/test_climb.py，照现有风格）

1. **回归**：`handover_mm=0`（默认 CFG）行为与现在逐字节一致——现有 73 测
   全绿本身就是断言，不用新写。
2. **相位序列**：δ>0 时窗头决策后进 HANDOVER，期间 `ctl.state` 保持
   ATTACHED、阀不动；δ/HANDOVER_SPEED_MMS 秒（±3 DT）后才 request_release
   进 VENT（照抄 test_vent_before_lift 的结构）。
3. **位移账**：交接完成时被抬腿目标 = 起点 + 上坡 δ，每条支撑腿 = 起点 +
   下坡 δ/5，y 分量按 _down 口径、z 恒在压入位；六腿位移矢量和 = 0
   （均值不变=身体指令不动的代数断言）。
4. **行走叠加**：带速度走，HANDOVER 期间被抬腿跟随支撑场（照抄
   test_vent_before_lift 的 XY 随场断言，叠加卸载分量后的期望值）。
5. **漏气暂停**：交接中注入支撑腿漏气，_ho_left 冻结不推进、不放气；
   挽救成功后续铺完成。
6. **冻结恢复**：交接中 frozen 注入，目标保持；clear_freeze 后续铺、
   完成、正常走完抬落（对比 test_single_step_hover_survives_freeze）。
7. **航向旋转**：wz 转过 θ 后交接方向随 _down 旋转（照抄
   test_sag_comp_downhill_rotates_with_heading）。
8. **原地抬落全程 IK 可解**：request_lift + δ=20 极限值，全程 pulses 可解、
   支撑足除交接分量外纹丝不动（对比 test_lift_in_place_hover_and_land_back
   ——注意该测试现有"支撑足纹丝不动"断言在 δ>0 时要改成"只动交接分量"）。
9. **δ 解析**：脚本层参数两种格式 + 越界拒绝（如果解析函数放引擎外，
   测试放脚本侧或直接单测解析函数）。

## 8. 实现清单（逐文件）

| 文件 | 改动 |
|---|---|
| `hexapod/config.py` | LegConfig.handover_mm 字段 + 注释（引本文档与报告） |
| `hexapod/climb.py` | HANDOVER_SPEED_MMS 常量；LegPhase.HANDOVER；`__init__` _ho_left；窗头决策分叉（§3.3）；第 4 步跟随集合加 HANDOVER（§4.1）；新 4.7 步（§3.4）；_step_swing pass 分支；模块 docstring 补 HANDOVER 段说明 |
| `hexapod/runlog.py` | PHASE_CH 加 "handover": "Z" |
| `scripts/body_lean.py` | --handover 解析 + 启动打印 + 文档头 |
| `scripts/climb_walk.py` | 同上（两边同步条款照旧） |
| `tests/test_climb.py` | §7 的 8 项 |
| `docs/P4-GUIDE.md` | 排障表"墙上原地踏步"行补零力交接入口（可选） |

## 9. 验收（实现完成的定义）

1. 全测试绿（现有 73 + 新增）。
2. mock 冒烟：body_lean --mock 带 --handover 走完整抬落轮。
3. **实机 A/B（下下步）**：重跑 08-20 原地踏步实验（同参数 + --handover
   起标表）——每轮下滑 74mm 应降一个数量级（<10mm）；整机电流不再逐周期
   爬升（保持 ~0.7-1.0A）；视频里 vent 无可见弹跳。量化管线复用
   （NCC 追踪，见报告"量化管线"脚注）。
4. A/B 过了再上 climb_walk：先单步、后连续，δ 微调，然后重测净前进率
   （26% 基线）。

## 10. 审核加固（2026-08-23，v1.6）

对 v1/v1.5 三提交的代码审查确认了 15 条问题（引擎 7 + 量化管线 8）。共性
根因：HANDOVER 相位按 VENT 的待遇写（"正在离场"），但它需要 STANCE 的待遇
（密封、承载、且正被系统性加减载）。引擎侧修复（全部入册 tests）：

1. **漏气监护覆盖交接腿**（_leak_watch 收 STANCE+HANDOVER）：原先交接腿
   本身脱管最长 δ/速率 秒——唇口中途失效时 4.7 步继续从一只已不承载的脚
   "还力"=储能照样瞬释。现交接腿漏气同样 leak_pause（铺设暂停不丢、不放
   气），挽救超时冻结点名；request_lean 的漏气守卫同口径。
2. **交接位移逐 tick 包络预检，越界截断**：4.7 步原是唯一没有钳制的支撑系
   推手（4.5 有 comp_tail 限额、4.6 有 _lean_room），δ 偏大/累积漂移时把
   支撑腿推出 IK 包络 → WorkspaceError 冻结，而 clear_freeze 保留在途交接
   （语义正确，保留），f 续铺同帧复冻=墙上死循环、oo 因非 STANCE 被拒、
   唯一出路 ESC×2 放气=坠落。现任一腿的本 tick 新目标越出安全包络（与
   _lean_room 同口径 _foot_xy_ok）即截断剩余量提前放气——部分卸载=弹跳
   打折但安全，handover_note 留痕（δ=25 反复抬同腿实测第 12 抬触发，全程
   不冻结、逐 tick IK 可解）。
3. **放气前门槛/互锁复检**：窗头判定距 request_release 已过 δ/速率 秒
   （漏气暂停/冻结+f 更久），期间支撑盘可漏到 −50 门槛之上、−20 漏气绊线
   之下的监护盲区——带着软肩膀放气正是 08-19 事故类。现铺完复检，不过则
   保持密封等泵（gate_wait 外显、共用 lift_gate_timeout_s 超时冻结）。
4. **权重轮转口径守卫**（§5 v1.5 段）+ **引擎口权重再验/归一化**：直设
   config 的路径原先不归一（(1,1,1,1,1) 每抬净下坡 +4δ 破坏零和）、CLI
   解析原先不拒 nan/inf（NaN 份额一路流到 joint_deg_to_us 被钳成 500µs
   端点脉宽）——两口都补验。
5. **δ 计入强制预算**：climb_walk 启动按 δmax ≤ comp_tail − 半步幅上限
   硬拒（与 --max-step 同级；出厂表 L1:17 在默认步幅 40 下超余量 16.8，
   文档示例已改 --max-step 38）；_lean_room 预扣在途交接（份额×剩余量）。
6. **均值不变的逐腿表破例**：见 §2 工程性质第二条 ⚠ 注（落地复位吞残差，
   首轮 ~4.8mm 上坡伪迹；稳态每轮漂移仍 0），A/B 判读纪律入协议。

量化管线（ab_quant.py）8 条另修：负偏移、climb_walk 日志、NCC 搜索半径、
--calib 覆盖、交接回看窗、轮次推导、缓存指纹、zoom 几何——见该文件头与
提交记录。

## 附录 A：1-D 弹簧模型（验证脚本，可直接跑）

```python
def sim(mode, cycles=300, u=40.0, mg=89.0):
    """y_i=锚点-指令; X=mean(y)-mg/n; 吸附零预载锁定 y_new=X。
    mg/k=89mm 由原地实测 74mm/轮反推。u=步幅(mm), 指令净前进=6u/5/周期。"""
    y = [0.0] * 6
    xs = []
    for c in range(cycles):
        for j in range(6):
            att = [i for i in range(6) if i != j]
            if mode == "handover":          # vent 前零力交接
                x6 = sum(y) / 6 - mg / 6
                fj = y[j] - x6
                y[j] -= fj
                for i in att:
                    y[i] += fj / 5
            for i in att:                   # 窗内支撑场扫 u/5
                y[i] += u / 5
            y[j] = sum(y[i] for i in att) / 5 - mg / 5   # 重吸附锁定
        xs.append(sum(y) / 6 - mg / 6)
    return xs[-1] - xs[-2]                  # 稳态净前进/周期

# 基线 u=40: 12.4mm (25.8%, 实测 26%); handover: 48.0 (100%)
# 基线 u=0: -35.6mm/轮 (实测 -74, 模型半量级——真机还有姿态非线性); handover: 0
```

模型已知的偏差：真机 lean 均匀指令亏 60%（线性模型预测 0%）——存在姿态
相关非线性损耗层，交接治不了它，靠标定/机械加刚；单腿储能有扭矩饱和上限
（~21mm），模型无此封顶。两条都不影响交接机构本身的正确性。

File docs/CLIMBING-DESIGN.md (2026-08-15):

# 爬墙方案设计论证

## 1. 吸附方式选型

| 方式 | 原理 | 适用墙面 | DIY 可行性 | 结论 |
|---|---|---|---|---|
| **真空吸盘 + 阀组** | 泵抽真空，每足独立阀控吸放 | 玻璃、瓷砖、烤漆、亚克力 | ★★★★☆ 全部标准气动件 | **主线** |
| EDF 负压压墙 | 涵道风扇把机器压向墙面 | 几乎所有平整墙面 | ★★★★☆ 航模件即得 | 放弃：只对 <800g 平台成立，与 2kg 大平台不兼容（见 §3） |
| 微刺（microspine） | 细针钩挂粗糙表面微观凸起 | 砖、水泥、粗糙涂料 | ★★★☆☆ 针+打印件即可，但单靠它承重需精细的柔性悬挂 | 放弃：需与 EDF 搭配才实用 |
| 磁吸 | 电磁/永磁 | 仅钢铁表面 | ★★★★★ | 场景太窄，放弃 |
| 静电吸附 | 高压电极极化墙面 | 多种 | ★☆☆☆☆ 高压+吸附力弱 | 研究级，放弃 |
| 仿生干胶（壁虎） | 范德华力 | 光滑面 | ★☆☆☆☆ 材料自制困难、易脏 | 研究级，放弃 |
| 热熔胶足 | 熔胶粘-加热脱 | 多种 | ★★☆☆☆ 循环慢、能耗高 | 放弃 |

### 腿数选型：为什么是六足而不是四足

四足省 6 舵机 + 2 套足模块（约 -450g / -¥300~500），但在墙上严格更危险：
摆动相吸附足数六足=5、四足=3；单吸盘脱吸（P2 验收即允许 5% 失败率，必然发生）后
六足剩 4 足可优雅降级重吸，四足剩 2 足承受动态冲击载荷，大概率连锁脱吸坠落。
另外四足单足峰值载荷 ×1.5（吸盘需升 40mm，重量优势缩水）、地面静步态要摆重心、
地-墙过渡只有"2+2"支撑。学术先例（広瀬 NINJA-I 四足吸盘爬墙）依赖研究级的
专用阀与高自由度腿，不适合 DIY。
**决定：六足。可逆后手：官方配置有 MODE_QUADRUPED，步态引擎加四足步态即可用
同一硬件 A/B 实测；若 P4 减重卡死，拆两条中腿转四足是随时可做的实验。**

## 2. 吸盘足方案力学预算

以 MakeYourPet 大平台 + 吸附系统整机 **m = 2.5kg**（余量上限）计：

- 单只 30mm 吸盘（配合 3D 打印抗形变外壳），工作真空度 -50kPa 实测：
  法向拉脱力 = **25N（2.5kg）**，竖直玻璃剪切拉脱力 = **15N（1.5kg）**（约为法向的 60%）。
- 爬墙步态下任意时刻最少 **5 只吸附**，极端保守按 3 只发生有效承力计算：
  法向总拉力 ≥ 75N，对 2.5kg(25N) 重力的**法向安全系数 = 3.0**
  剪切总拉力 ≥ 45N，对 2.5kg(25N) 重力的**剪切安全系数 = 1.8**（若按 5 只有效，则剪切安全系数达 3.0，余量非常充足！）
- 剥离力矩：重心离墙 d，上排吸盘受额外拉力 ≈ m·g·d/h（h 为上下足距）。
  d 每减 1cm 都是实打实的余量 → **爬墙姿态身体尽量贴墙、电池等重物靠墙侧安装**。

系统结论：
1. 30mm 吸盘 ×6 + -50kPa 对 2.5kg 内的整机成立；负重阶段换 40mm（面积 ×1.78）。
2. 泵只需维持储气罐真空，阀负责各足吸放 → 泵可间歇工作省电。
3. **常闭阀 + 单向阀**让断电状态=全足吸附锁定，这是最重要的被动安全设计。

## 3. 已放弃路线的论证记录：EDF 压墙

粗糙墙面（砖、水泥、乳胶漆）的常见 DIY 方案是涵道风扇把机器压向墙面 + 摩擦/微刺足。
放弃原因（平台定为 MakeYourPet 大平台后由物理否决）：70mm 12 叶 EDF @4S 静推力仅
12~18N；摩擦系数 μ≈0.6 时防滑需 F_press ≥ m·g/μ，2kg 整机需要 33N+ 的持续压紧力，
意味着双 90mm EDF、数百瓦功耗、且风扇一停就掉——与"静态停留、可负重"的项目目标冲突。
此路线仅对 <800g 的轻量平台成立（参考文献见 §7 的 GECO 与 IJERT 论文）。
**结论：本项目只做光滑墙面（玻璃/瓷砖/烤漆），粗糙墙面不在范围内。**

## 4. 气路图

```
泵(555×2 并联) → 单向阀 → 储气罐(PET瓶) ─┬→ 常闭三通阀#1 → 足1吸盘
      ↑                    │(XGZP6847A     ├→ 常闭三通阀#2 → 足2吸盘
  MOSFET板←Pi5 GPIO        │ 压力反馈,      ├→ ...
           Pi5 I2C←ADS1115←┘ 经ADS1115)    └→ 常闭三通阀#6 → 足6吸盘
   三通阀第三口 = 大气（通电切换到放气位，释放该足）
```

控制逻辑（吸附状态机，每足独立）：
`RELEASED → 压紧墙面 → 阀切吸气位 → 等待压力 ≤-30kPa（超时500ms则抬脚重试）→ ATTACHED（允许承重）→ 需要移动时阀切放气位 → 延时300ms → RELEASED`

步态约束：**任意时刻至少 5 足处于 ATTACHED**，且相邻足不同时释放。

> [!TIP]
> **电磁阀断电保压的神级接法 (P1 阶段总结)**
> 采购的 0520B 类常闭三通阀实测行为：断电时孔 1 与孔 3 连通，孔 2 封闭。
> 为了实现“断电 = 吸盘保持真空”的被动安全设计，**必须采用以下接法**：
> 1. 孔 1 ➡️ 接吸盘
> 2. 孔 3 ➡️ 接真空泵抽气口
> 3. 孔 2 ➡️ 放空通大气
> **原理解析**：断电时（1通3），吸盘连着停转的真空泵，利用隔膜泵内部的单向阀实现死锁保压。通电时（1通2），吸盘接通大气孔泄压抬腿。此接法不仅实现了绝对的断电防坠落安全，而且在静止吸附时电磁阀 0 耗电。代码中需配置 `VALVE_ON_LEVEL=0`。

## 5. 电气架构演进

**单脑架构：树莓派 Pi 5 从第一天就是大脑**（`software/` 自研软件，全阶段同一套代码栈）：

```
2S 电池 ─┬─ 7.4V 直供 → Servo2040 舵机电源轨(经继电器) → 18 舵机
         ├─ 5V/5A 降压 → Pi 5 (USB-C，独立供电，绝不与舵机共轨)
         └─ XL6009 升压 12V → MOSFET板 → 6 阀 + 2 泵
Pi 5 ─USB──→ Servo2040（chica 串口协议：18 舵机 + 6 足底开关 + 电压/电流）
Pi 5 ─I2C──→ ADS1115 ×2 → XGZP6847A 压力传感器（P1 起）
Pi 5 ─GPIO─→ MOSFET 板（阀/泵开关，P1 起）；GPIO17 → 舵机继电器（P4 起）
Pi 5 ─CSI──→ 摄像头模块（P5，FPV）
```

- 协议说明与驱动实现见 `software/hexapod/driver.py`（已按固件源码逐字节核实）。
- 步态每挪一步前先由吸附状态机确认"目标足已吸附"（`software/hexapod/adhesion.py`）。
- **必装低压报警**：锂电欠压=泵停=吸附衰减=掉落。软件层 `check_power()` 在 6.0V 以下直接抛异常停机（阀常闭，断电仍保持吸附）。

## 6. 活动度分析：3DOF 腿能否上垂直墙

分析脚本 `tools/workspace_analysis.py`（用真机连杆 43/80/120mm——tibia 为 L1 实测值，
见 LEG-GEOMETRY-OPEN §2.11——与舵机电气行程 femur -40.3°~+139.7°（L1 实测 attach 49.7°，
§2.12）、膝内角 0°~176.4° 计算；2D 腿平面模型，保守。2026-07-17 按实测标定重算；
**2026-07-18 修正吸盘轴模型**：物理吸盘轴沿方轴 = a_t − 22.7°，不等于 K→P 连线方向
a_t（膝轴 K 偏离方轴 46.5mm 的固定几何差，LEG-GEOMETRY-OPEN §2.13），下表已按此重算）。
3DOF 腿的本质限制：**足端位置与吸盘朝向耦合**——选定落足点后吸盘轴向就定了，
只能靠波纹吸盘的角度顺应性兜底。

**A. 在墙上行走：可行。** 身体平行墙面时与地面行走运动学等价，唯一新约束是
吸盘轴线相对墙面法线的偏角（波纹吸盘容差约 15°）：

| 站高（身体离墙） | 支撑相 reach | 步幅 | 吸盘轴偏角 |
|---|---|---|---|
| 90mm | **170mm** | 0 / 30 / 40 / 60mm | 1.6° / ≤8.9° / ≤11.5° / ≤17.2° |
| 90mm | 130mm（地面默认） | 0mm | **16.7°，超容差** |
| 70mm | 170mm | 0 / 30 / 40mm | 5.0° / ≤11.5° / ≤13.9° |

→ 爬墙步态用 **站高 90mm + 支撑相 reach 170mm + 步幅 ≤40mm**（偏角 ≤11.5°）。
关键变化（2026-07-18）：**墙上不能沿用地面 reach=130 的姿态**——那会让吸盘以
16.7° 斜角接墙；上墙时足端要外展到 reach≈170。"身体贴墙"（降剥离力矩）与
"吸盘对正"方向相反，90mm 仍是平衡点。

**B. 地-墙过渡（前足上墙）：运动学上有解。** 前腿可落足区（偏角容差 15°，
相对前髋的高度范围，mm）：

| 身体俯仰 | 墙距前髋 100 | 140 | 180 |
|---|---|---|---|
| 0°（平身） | +75~+143 | +95~+153 | +95~+141 |
| 30°（绕后髋抬头） | +96~+168 | +116~+174 | +114~+158 |

→ 修正吸盘轴后可落足带反而**更宽更高**（约 50~70mm 高、位置整体上移）：平身墙距
80~200mm 全部存在可行落足点；身体俯仰 30°（`robot.py` 的 `body_rpy` 已支持）后
更宽。过渡序列每一步都有解，但序列编排复杂，仍按路线图放在 P5。

**结论与设计决策：**
1. 不需要给腿加第 4 个踝关节舵机——省下 6 个舵机的重量和复杂度。
2. 可行性的关键参数是波纹吸盘的实际角度容差。**P1 台架实测结果：斜角容差达到了 15°！** 这意味着我们可以满额释放机器狗的机动能力，采用 **40mm 的大步幅**进行爬墙，无需收紧到 25mm。
3. 以上用电气行程计算，未计结构干涉（femur 撞机身、tibia 撞 femur）——P2 单腿
   试验时实测各关节的真实机械行程并回填本分析。

## 7. 参考项目与文献

- MakeYourPet 六足（本仓库 `hardware/makeyourpet-hexapod/`，MIT）：https://github.com/MakeYourPet/hexapod
- Aecert Robotics 六足（Arduino 全教程系列）：https://aecertrobotics.com ，代码 https://github.com/Ryan-Mirch/Aecerts_Hexapod_V1
- GECO 爬墙机器人（根特大学，EDF 负压，§3 已放弃路线的参考）：https://www.instructables.com/GECO-Wall-Climbing-Robot/
- Sub-1kg EDF 爬墙机器人设计（IJERT, 2026，§3 已放弃路线的参考）：https://www.ijert.org/design-and-development-of-a-sub-1-kg-wall-climbing-robot-using-electric-ducted-fan-for-vertical-surface-operations-ijertv15is043914
- 爬墙机器人技术综述（ScienceDirect, 2024）：https://www.sciencedirect.com/science/article/pii/S2773186324000781
- 被动吸盘爬墙机器人设计：https://www.researchgate.net/publication/251991762_Design_of_a_wall-climbing_robot_with_passive_suction_cups

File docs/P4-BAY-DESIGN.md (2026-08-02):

# P4 电气+气动舱固定件 · 设计方案

目标:把 P4 吸附系统的全部电气/气动器件收进**一个可整体拆下的"舱"**,
固定在 MakeYourPet 机身(frame)顶面,几颗 M3 下机。现有实测尺寸已生成
**V0 试装版 STL**；生成器为独立的 `tools/generate_p4_bay_v0.py`,输出到
`hardware/climbing-parts/p4-bay-v0/`。V0 必须先通过 1mm 外廓模板和器件试装,
不能未经实装复核直接用于爬墙。

依据材料:
- 实物照片 `dianqi.jpg`(器件安装特征盘点的第一手来源)
- 连接拓扑 `html/p4-system-diagram.html`(电气三路 + 真空母线,决定相对位置)
- `docs/P3-GUIDE.md` 第 2 步"P4 气动舱固定件"行(已定约束:泵 TPU 软固定、
  阀阵列梁、罐抱箍、7 路传感器位+感测三通、PCB 柱、理线梳、整舱可拆、
  大质量件贴机身平面摊平、每腿服务环)
- 官方 `component-layout.jpg` + STL 实测:frame 198×205×16mm,
  top-cover4 占位 100×140mm,腹面另有 battery-bar(电池)与
  servo2040-bottom-cover(Servo2040 托盘)

---

## 0. 三个先定下来的架构决定

1. **电池和 Servo2040 不进舱,留在官方腹面位。**
   官方件 battery-bar(电池绑腹面)+ servo2040-bottom-cover(Servo2040 托盘)
   在 P3 打印清单里本来就要打。爬墙时腹面朝墙——电池是最重单件(~350g),
   放腹面恰好是全机离墙最近的位置,重心最优;18 根舵机线也天然在腹面汇聚。
   把它们搬上舱只有坏处。舱只需要:给 Pi↔Servo2040 的一根 USB 留下潜通道,
   给电池 XT60 线束留上行通道。
2. **"Servo2040 靠 Pi"立体实现。** Pi 放在舱前部、frame 中央开口正上方,
   Servo2040 在开口正下方的腹面托盘——两者垂直相邻,一根 15~20cm USB-C
   线穿开口直达。既满足"一根 USB 连线短",又不动 18 根舵机线。
3. **舱做上下两层:气动件贴底、电路板上甲板双面安装。** 原规划的
   110×95mm 夹层面积仅 10450mm²,而 Pi+分压板+5V 板自身面积已达
   12234mm²,物理上放不下。V0 改为 184×108×3mm 六柱电气甲板:
   Pi/分压板/5V 在顶面,MOSFET/继电器/2×XL6009 在底面;泵、阀、歧管和
   传感器仍贴底板。柱长改为 90mm,为泵、未来 Ø≤70 储气罐和甲板底面
   器件留出净空。

---

## 1. 器件清单与安装特征盘点

固定策略类型:**A** M3/M2.5 螺柱直锁(板上有孔)/ **B** 打印卡扣托盘(无孔板)/
**C** TPU 软垫+压条(泵)/ **D** 抱箍(圆柱体)/ **E** 扎带槽(线束、轻小件)。

| # | 器件 | 照片观察到的安装特征 | 固定策略 | 减震 |
|---|---|---|---|---|
| 1 | Raspberry Pi 5(贴 4 片铜散热) | 标准 4×M2.5 孔(58×49mm 孔距);USB-C 电源口与 micro-HDMI 同侧,USB-A/网口在对侧 | A:M2.5 穿板螺丝+6mm 隔柱;电气甲板顶面 | 不需要;散热片上方留 ≥15mm 空气层,不加顶盖 |
| 2 | 2S 锂电(银色碳纹硬壳,XT60+平衡头) | 无任何安装孔/支架,光壳 | **不进舱**:官方 battery-bar + 魔术贴/扎带,腹面;充电可拆 | 不需要 |
| 3 | 555 真空泵 ×2(黑泵头+银电机) | **自带金属 L 支架**,实测 48×28mm 四孔、孔 Ø5 | C:独立适配板+4×M4+大垫圈,支架与板之间垫 3mm TPU 片,"贴住不压死"；V0 先装单泵 | **必须**(隔膜泵震动:硬锁会松螺丝+传感器毛刺读数,P3-GUIDE 已定) |
| 4 | YYNMOS-8 八路 MOSFET 板 | 实测 93×54mm,四孔为非对称坐标;两长边均为蓝色端子 | A:M3 穿板螺丝+6mm 隔柱;电气甲板底面,**输出端子朝阀轨,输入端朝 XL6009** | 不需要 |
| 5 | 5V 降压模块(USB-C 输出,"QC PASS"贴纸) | 实测 46×24mm、41×19mm 四孔、Ø3;USB-C 在短边正中 | A:M3+6mm 隔柱,装电气甲板顶面;**USB-C 出口对准 Pi 的电源口一侧** | 不需要 |
| 6 | XL6009 升压 ×2(红板,电位器+蓝端子) | 实测 50×28mm、43×21mm 四孔、Ø3;发热件 | A:M3+6mm 隔柱,装电气甲板底面;电位器侧留手调空间 | 不需要 |
| 7 | Servo2040 | 4×M2 孔,USB-C 一端,18 路三针排针两侧 | **不进舱**:官方 servo2040-bottom-cover,腹面 | 不需要 |
| 8 | 0520B 电磁阀 ×6(照片×1,电磁铁+白宝塔嘴) | 无安装支架、无孔——就是一颗带嘴的电磁铁 | B 变体:**打印阀轨**(6 槽负模卡位)+ 压条/扎带 | 不需要(阀是激励源之一但质量小,刚性固定即可) |
| 9 | 分压汇接板(大洞洞板 + 2×ADS1115 半成品) | 实测裁切后 91×70mm、孔距 83×58、Ø3(制作图纸见 html/p4-divider-board.html) | A:M3 穿板螺丝+6mm 隔柱;甲板顶面,**紧邻 7 路传感器线上行口 + IDC 排线到 Pi 40pin** | 不需要 |
| 10 | XGZP6847A 压力传感器 ×7 | 实测 19×19×12mm(不含针脚),Ø3 取压嘴向上、针脚向下,无安装孔 | B 变体:**打印 7 槽传感器排座**,针脚穿底窗,卡入后用少量中性硅胶点固 | 轻度:排座整体远离泵位,靠 TPU 泵垫切断震源即可 |
| 11 | 真空歧管(1 进 6 出) | 实测主干 Ø20×115,出口节距 17,无安装耳 | D 变体:内径 20.6 的 C 形卡座 ×2 + M3 | 不需要 |
| 12 | 储气罐(汽车真空罐,未到货) | Φ50~70×100~150 估;BOM 注明**自带宝塔嘴和安装耳** | D:鞍形抱箍 ×2 + TPU 内衬 + 扎带/魔术贴;有安装耳则耳孔直锁优先 | 不需要(上机前先单独抽 −70kPa 压瘪测试) |
| 13 | 舵机电源开关(30A 继电器模块) | 实测 72×40mm、孔距 66.5×34.5、Ø3 | A:M3 穿板螺丝+6mm 隔柱;电气甲板底面,**切正极高边**,靠近电源入口 | 不需要 |
| 14 | XT60 线束 + 总开关(KCD1船型) | KCD1 实测开孔 19×13;XT60 仍无板式卡槽尺寸 | E + 面板支架:1.8mm 卡扣壁+XT60 双扎带槽("随手可拔"位) | 不需要 |
| 15 | 单向阀 ×2、三通 ×7、硅胶管 | 全部管路件,无安装特征 | E:底板扎带槽阵列就近锚定 | 不需要 |

---

## 2. 布局方案(核心)

### 2.1 分区总图(俯视 frame 顶面,头朝上)

```
                        前(头)
         FL 腿 ◤                        ◥ FR 腿
   ┌────────────────────────────────────────────┐
   │ ══ 电气甲板(184×108,六柱高 90,双面) ═════   │
   │  ┌─────────┐  ┌──────────────┐              │
   │  │ 5V降压  │→ │  Pi 5        │  ┌─────────┐ │
   │  │USB-C 对口│  │ (40pin 朝后) │←→│ 分压汇接板│ │
   │  └─────────┘  └──────┬───────┘IDC│+2×ADS   │ │
   │                      │USB 下潜   └────┬────┘ │
   │        (frame 中央开口:正下方腹面     │7路线  │
   │         = Servo2040 官方托盘)         ↓下层  │
   ├──── 电气甲板底面(功率电气)───────────────┤
   │  [继电器留位70×30] [XT60+总开关↗右前缘立面]  │
   │  [XL6009 ×2 并排]→[MOSFET 板(输出端朝后)]   │
   ├──── 下 层 板(中部:阀区,对齐 ML/MR 腿)────┤
 ML│ ◄3 路出管   [传感器排座 4+3 双排]   3 路出管► │MR
   │        [ 阀 轨:0520B ×6 一字排 ]             │
   │        [ 歧管 1进6出,紧贴阀轨后侧 ]          │
   ├──── 下 层 板(后半:真空发生链)─────────────┤
   │  [V1 储气罐:到货实测后再定抱箍和位置]          │
   │  [泵1 ▓] L支架+TPU垫；第二泵只保留同型适配方案 │
   │      └单向阀短管→歧管/未来储气罐               │
   └────────────────────────────────────────────┘
         RL 腿 ◣                        ◢ RR 腿
                        尾
   腹面(爬墙时朝墙):电池(battery-bar+魔术贴) + Servo2040(官方托盘)
```

V0 底板外形 **190×130mm**(中央区域复用 top-cover4 的 100×140 接口边界,
左右外扩翼压在 frame 顶面实心区上,避开 6 个 coxa 舵机区——净空待实测 §4-14)。
V0 下层名义中心坐标为:阀轨 `(0,-48)`,泵适配板 `(-52,22)`,传感器座
`(45,22)`,两只歧管卡座 `(-55,-18)/(55,-18)`；歧管轴心为
`(0,-18,z=37)`。原点=底板中心,+Y 朝头,完整孔位见
`hardware/climbing-parts/p4-bay-v0/layout-report.json`。

### 2.2 逐条核对布局原则

| 原则 | 落实 |
|---|---|
| 大质量件贴机身平面摊平 | 电池(最重)在腹面=离墙最近;V0 单泵、阀、歧管贴底板;甲板只放 PCB。储气罐到货后仍优先贴底,但必须先按实测尺寸做 V1 抱箍 |
| XL6009 出 12V 紧邻 MOSFET 功率端 | 前半区并排,端子对端子,电源线 <50mm |
| MOSFET 输出端朝阀阵列 | 板输出侧朝后,正对中部阀轨,6 根阀线 <80mm;2 根泵线沿右缘理线梳到尾部 |
| 分压板紧邻 7 路传感器接入 | 分压板在夹层后缘,**正下方就是传感器排座**,7 路线垂直上行 <60mm;到 Pi 走 2×20 IDC 排线(P3 已定,禁杜邦) |
| Servo2040 靠 Pi(一根 USB) | 垂直相邻(§0-2),USB-C 线穿 frame 中央开口 |
| 5V 降压 USB-C 出口对 Pi 口 | 降压模块在 Pi 电源口同侧,出口对准,用 15cm 短线 |
| 气路一条龙 | 尾→前一直线:泵×2 →单向阀×2 →罐→罐口三通(罐压传感器=排座第 7 槽)→歧管→6 阀;全链在后半+中部连续,无跨区长管 |
| 6 阀出口朝六腿分散 | 阀轨横贯中部、正对 ML/MR 腿根;3 路出管向左、3 路向右,沿底板边缘扎带槽走到各腿根,**每腿过 coxa 留服务环**(松弛圈),舱缘扎带槽是最后锚点 |
| 泵震动隔离 | 自带 L 支架 + 3mm TPU 片 + TPU 垫圈,半浮动锁法(§3-3) |
| 电池可拆 | 腹面魔术贴/扎带,充电即取,不动舱 |
| 模块化 | 整舱一块底板,4~6 颗 M3 下机;电气甲板 6 颗 M3 柱,单独可拆;泵/阀/传感器/歧管固定件均通过孔阵列单换 |

### 2.3 高度与接口

- V0 底板 3mm,周边/开口加强筋再高 5mm,总高 8mm；电气甲板 3mm。
- 六根甲板柱长 90mm,甲板底面距底板平面约 93mm。按泵安装面+3mm TPU+
  支架轴高 28mm+电机半径 19mm 估算,泵顶约 58~60mm；余下约 33mm,
  扣除 6mm PCB 隔柱、约 2mm 板厚和保守 15mm 元件高度后还有约 10mm
  静态余量。打印柱仅供试装；正式爬墙优先换 M3×90 金属/尼龙六角柱或
  两段组合柱。泵和甲板底面 PCB 之间仍要实装
  检查端子、线弯和振动摆幅,不可只看静态包络。
- 与 frame 接口复用 top-cover4 四孔 `(±44,±40)`；V0 另预留 `(±44,0)`
  两个加强孔。后两孔须在 1mm 模板确认后才给 frame 钻 Ø2.8mm M3 自攻底孔,
  不确认不得钻。
- 底板中央开口为 70×108mm、R14,小于 frame 最小通孔 76×116mm、约 R18；
  用于 USB/传感器线/舵机线下潜。190×130mm 外廓到 coxa 线束的动态净空
  仍须用 `p4-bay-fit-template-v0.stl` 在装好腿和线夹的 frame 上复核。
- 泵排气口朝尾外,阀的侧向 Ø6 接口从阀轨开放侧伸出；12V 功率线和模拟
  传感器线使用不同理线梳。
- 走线纪律(P3 遗留):12V 功率线与 0.25~2.25V 模拟传感器线**分梳走线**,
  不同理线梳、不并捆;全舱禁面包板/杜邦,JST-XH 或焊线。

### 2.4 重量预算——先泼冷水

2.5kg 总预算 − P3 无吸附参考线 1.9kg = **吸附系统隐含预算仅 0.6kg**。粗估:

| 项 | 估重 g |
|---|---|
| 泵 ×2 | ~260 |
| 罐 | 60~100 |
| 阀 ×6 | 120~200 |
| 歧管+管路+接头+单向阀 | ~120 |
| 传感器 ×7 | ~40 |
| MOSFET + XL6009×2 + 分压板 | ~140 |
| 舱打印件 + 螺柱螺丝 | 200~250 |
| **合计** | **~940~1110** |

**超支 ~350~500g。**对策(按优先级):① 首飞只装单泵,双泵位留着、备泵
在架子上(−130g);② 罐选小号 250mL;③ 打印件以减重为一级目标——3mm 板
+镂空+筋,目标 ≤180g;④ 每件到货即称重记 `weight-log.md`,超 2.2kg
(无吸附)或预估整机超 2.7kg 时启动减重专项。**2.5kg 大概率守不住,
真实落点估计 2.6~2.8kg——这直接吃吸附裕量,P4 验收前要重算吸盘数值账。**

V0 按清单数量(不含 1mm 模板)的几何实体体积约 **237.2cm³**；若全部按
实心 PETG/TPU 计算,质量上限约 **301g**。切片器填充会降低实重,采购柱/隔柱
也会改变结果,但 3mm 大平板大部分仍接近实心。故 V0 的任务是确认孔位、
装配和线束,不是宣称达到 ≤180g；试装通过后再做 V1 镂空/薄壁减重并实称。

---

## 3. 每个固定件的设计说明

| 件 | 形式与要点 | 大概尺寸 | 材料/打印取向 | 与底板接法 |
|---|---|---|---|---|
| bay_baseplate 底板 | 独立 20/24mm 模块孔阵列、70×108 R14 下潜口、周边+开口加强筋；不把器件凸台焊死在大板上 | 190×130×3,总高 8 | **PETG**;平躺,无支撑 | 原 4×M3 + 可选 2×M3 加强孔锁 frame |
| electrical_deck 电气甲板 | 顶面 Pi/分压板/5V；底面 MOSFET/继电器/2×XL6009；保留 3 个穿线槽 | 184×108×3 | PETG;平躺 | 六柱,柱孔 `(±85,-48/0/48)` |
| deck_post / pcb_spacer | 90mm 空心柱供试装；PCB 分别用 6mm M2.5/M3 隔柱 | Ø9×90 / Ø7×6 | PETG;立打柱只用于试装 | 正式件优先采购六角柱/组合柱 |
| pump_adapter + TPU pad | 适配板上 48×28 四孔 Ø5.4,供 4×M4+大垫圈；四条 M3 长槽锁左侧孔阵列；TPU 垫 3mm | 64×54×4 / 58×38×3 | PETG + TPU 95A;平躺 | V0 单泵,第二泵复用同件 |
| valve_rail 阀轨 | 6 槽,节距 23；每阀底部开窗避让垂直 Ø6 嘴,四角小挡块定位,开放侧让侧向嘴出管 | 154×34×10 | PETG;槽口朝上 | 两端 M3 长槽；每阀 1 条 2.5mm 扎带上压 |
| sensor_block 传感器排座 | 4+3 双排 7 槽,节距 21.5；底窗避让针脚；另开 2×Ø11 让右侧甲板柱直接落到底板 | 104×64×11 | PLA/PETG;槽口朝上 | 右侧孔阵列 4×M3；中性硅胶点固 |
| manifold_clip 歧管卡座 | 主干 Ø20 的开口 C 卡,内径 20.6；轴心抬到 z=37(装配坐标),从阀轨后上方跨过 | 30×约27×45.9 | PETG;底面朝下 | 每座 2×M3,共打印 2 个 |
| tank_cradle 罐抱箍 | **V0 不生成**；储气罐仍未到货,不能用估算直径做承力件 | 待 §4-11 | — | 到货实测后生成 V1 |
| switch_bracket 电源面板 | 1.8mm 局部壁厚+19.4×13.4 KCD1 方孔；XT60 尺寸未量,改用相邻双扎带槽,不做假精确卡槽 | 50×20×33 | PETG;侧躺或加支撑 | 底面 2×M3 长槽 |
| cable_comb 理线梳 | 5 槽梳齿件 ×4；功率、模拟信号分件使用 | 48×14×16 | PLA/PETG | 每件 2×M3 |

---

## 4. 待实测尺寸清单(拿卡尺,量完填空)

实物图为可点击缩略图；同一器件的正反面或多角度照片放在同一格。

| # | 实物图 | 器件 | 要量什么 | 实测值(填这里) |
|---|---|---|---|---|
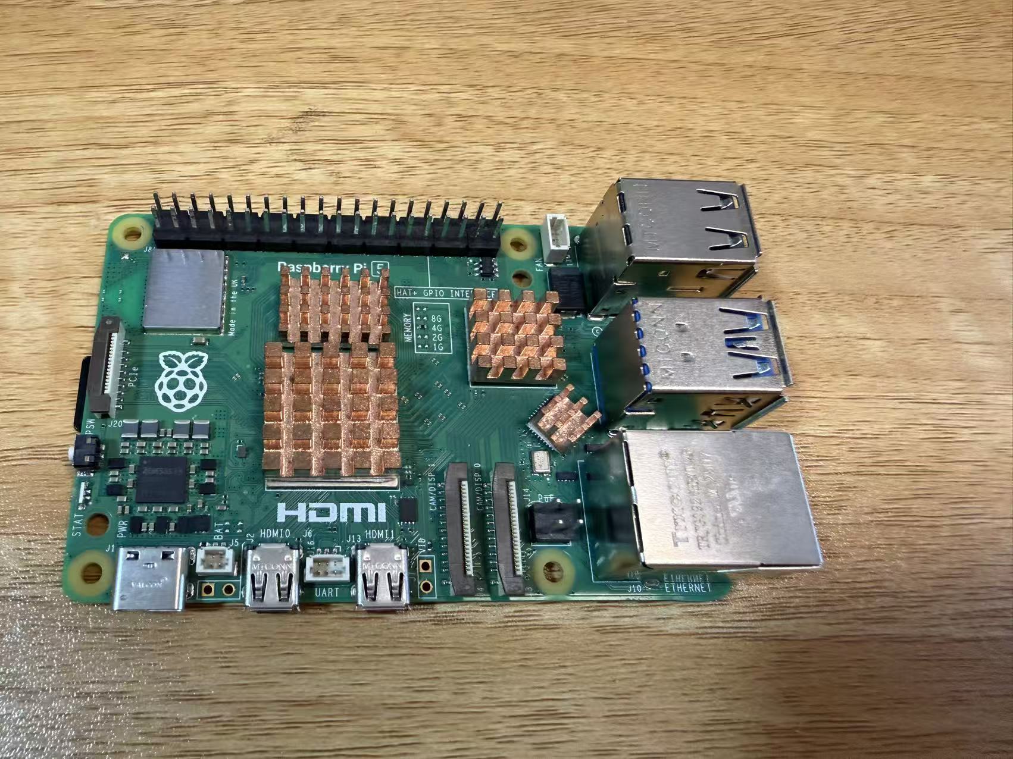
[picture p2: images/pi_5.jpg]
Pi 5
| 1 |  | Pi 5 | 4 孔孔距(标称 58×49)复核、孔径(标称 Ø2.7)、USB-C 口中心距板角 | _58_×_49_ / Ø2.7__ / __12__ |
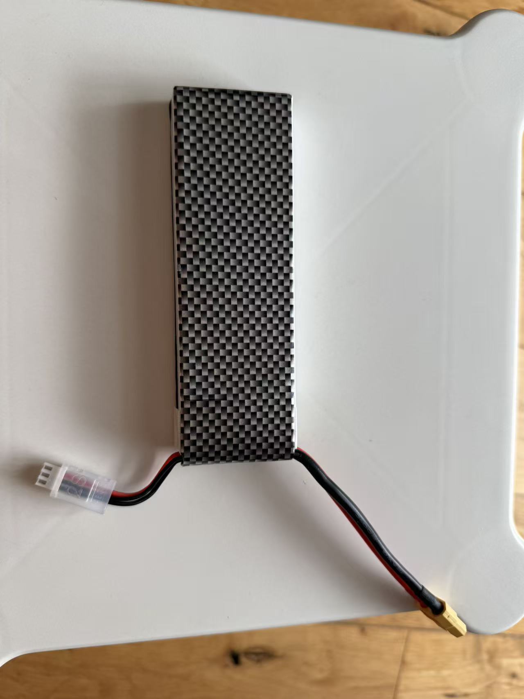
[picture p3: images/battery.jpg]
2S 电池
| 2 |  | 2S 电池 | 长×宽×高、XT60 线长(腹面官方位用,舱只留线束通道) | _135_×__43__×__16__ / __90__ |
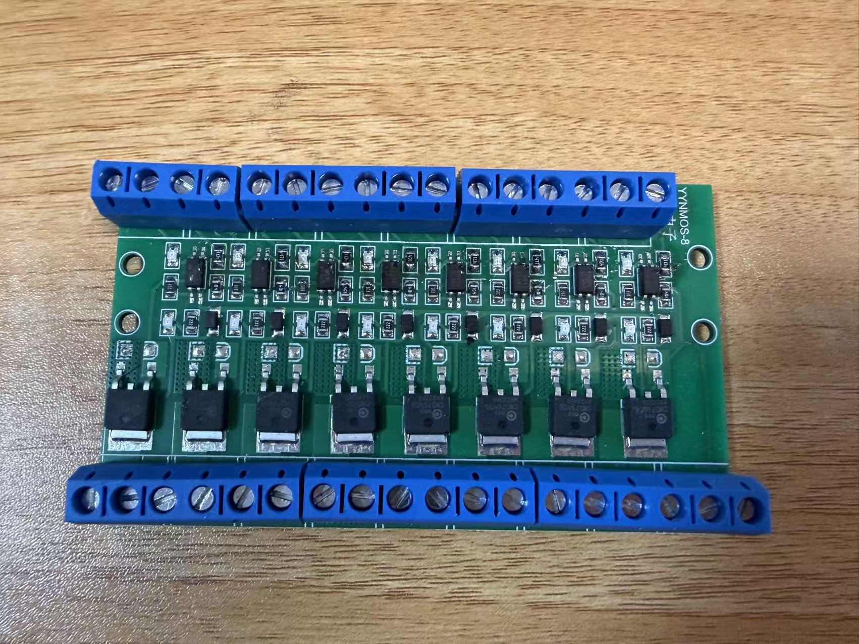
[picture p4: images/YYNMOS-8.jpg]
YYNMOS-8 正面
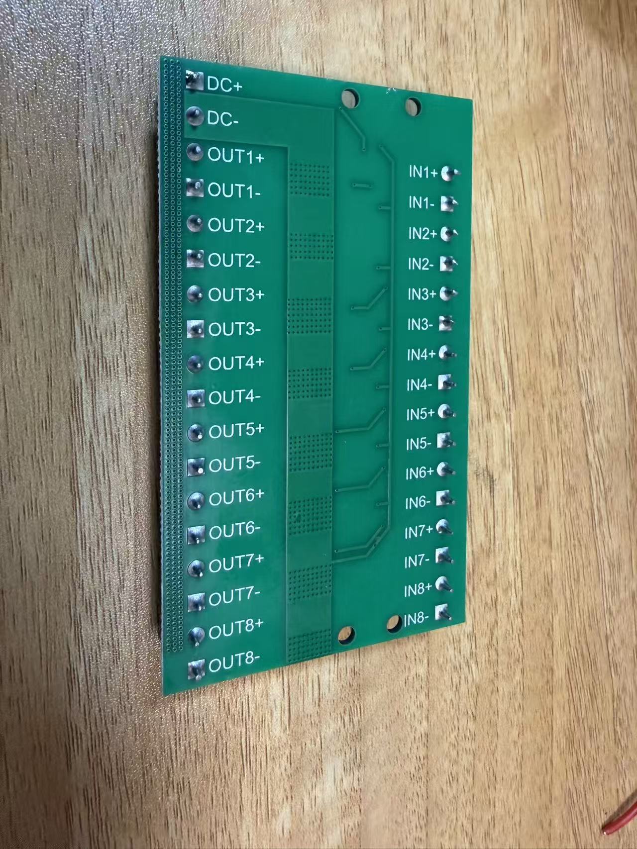
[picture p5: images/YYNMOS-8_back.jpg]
YYNMOS-8 背面
| 3 | <br> | YYNMOS-8 | 板长×宽、4 孔坐标、两侧端子排距板缘距离 |  _93_×__54_ / 4个孔距左下角的(X,Y)坐标分别为： 孔1(左下): (3, 30) 孔2(右下): (90, 30) 孔3(左上): (3, 39) 孔4(右上): (90, 41.5) 孔径：Ø 3.0 / 两侧端子排距板缘距离：左 内缩 1mm, 右 内缩 1mm |
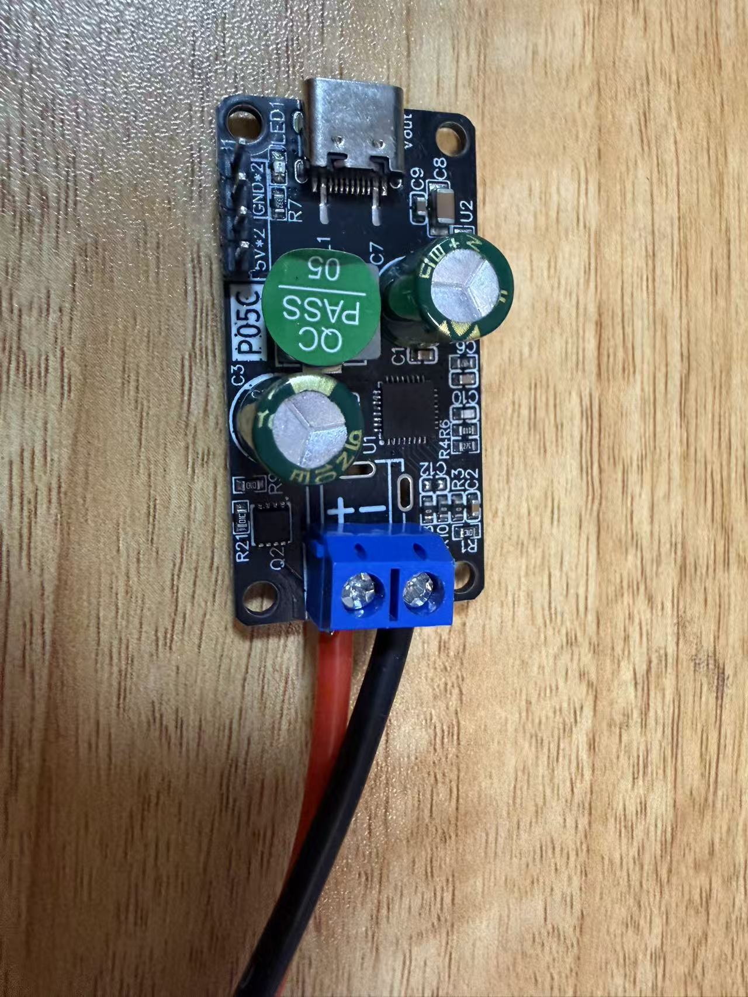
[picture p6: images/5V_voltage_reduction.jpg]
5V 降压模块
| 4 |  | 5V 降压模块 | 板长×宽×厚、**有无安装孔**(有则孔距/孔径)、USB-C 口朝向 | __46__×__24__×__17__ / __有安装孔，孔距41x19，孔径 3_/ USB-C 口 在短边，正居中 |
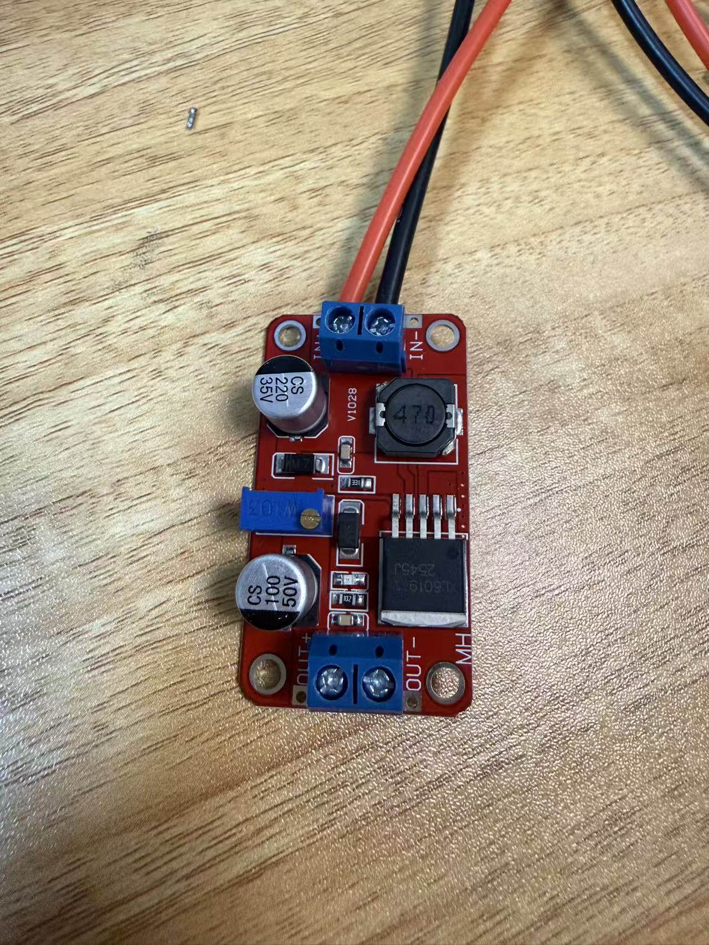
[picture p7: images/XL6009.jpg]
XL6009
| 5 |  | XL6009 ×2 | 板长×宽、**有无孔**(孔距/孔径)、两块是否同款、电位器位置(要留手调空间) | _50_×_28__ / __有安装孔，孔距43x21，孔径 3_ |
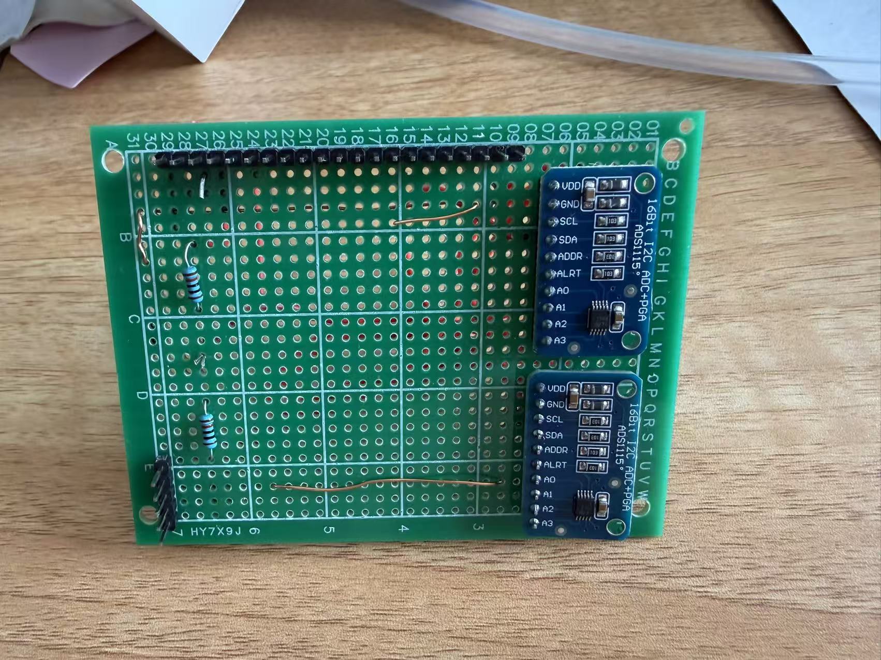
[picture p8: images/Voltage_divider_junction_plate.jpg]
分压汇接板
| 6 |  | 分压汇接板 | **裁切后**长×宽、四角孔距×孔径(先定裁切线再量) | __91__×__70__ / __83__×__58__ Ø_3__ |
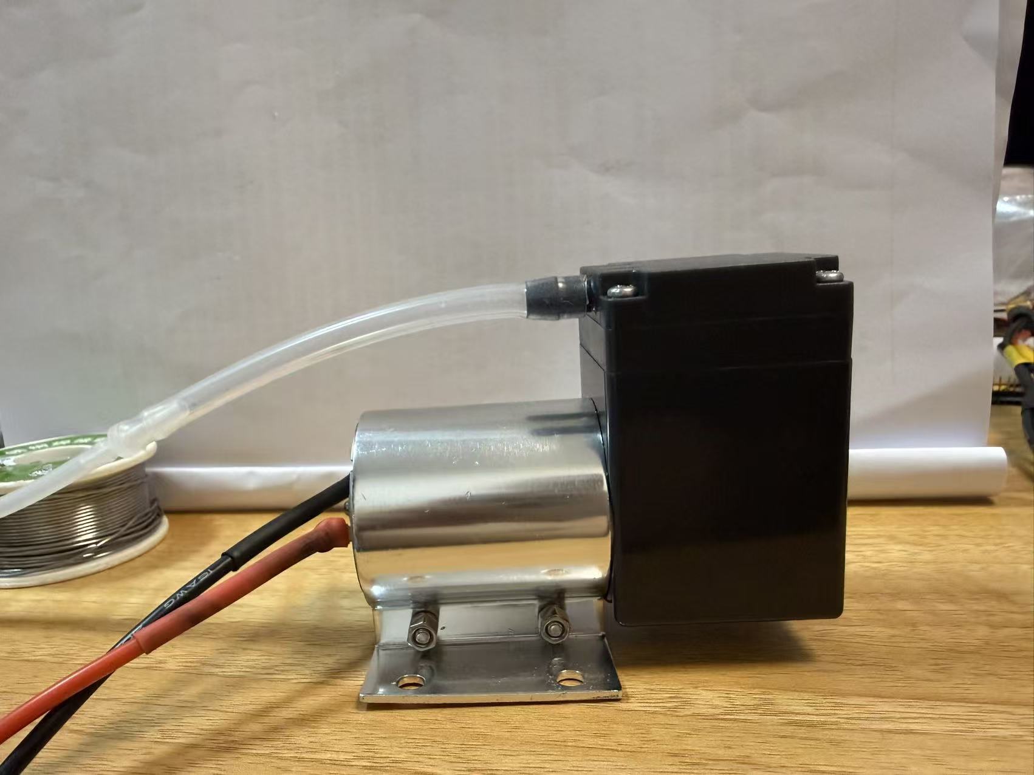
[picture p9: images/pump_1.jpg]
555 泵侧面
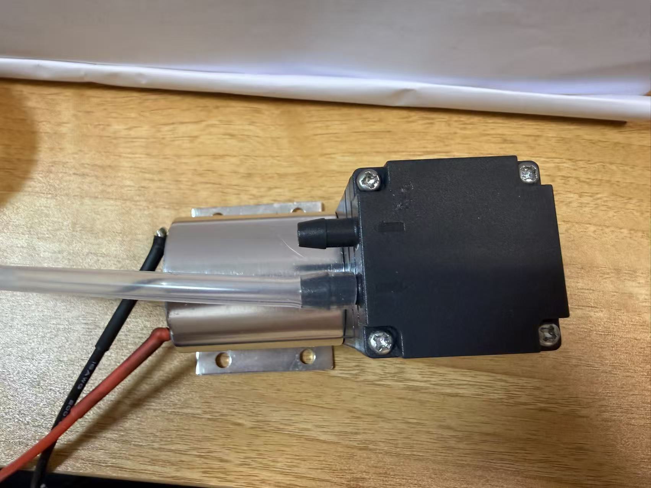
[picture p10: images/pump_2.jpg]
555 泵顶面
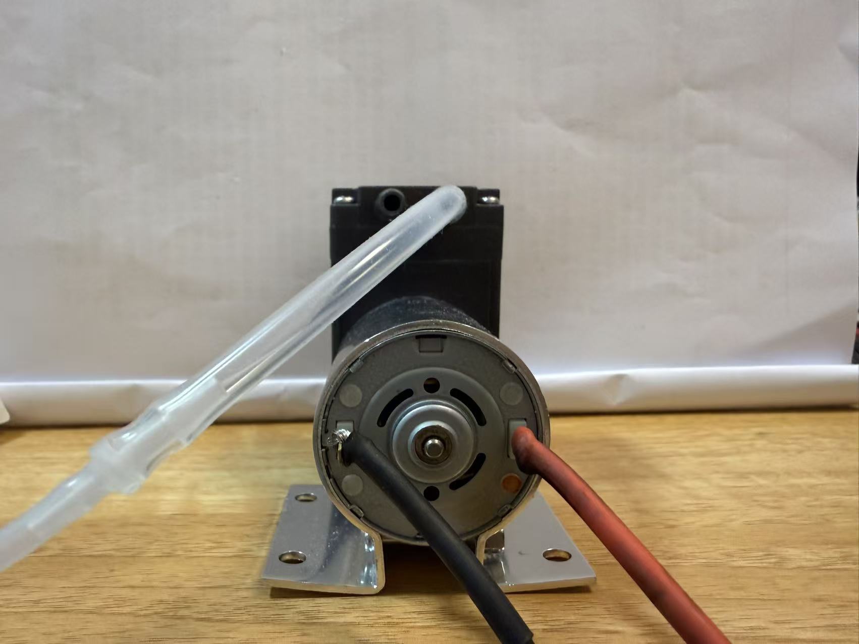
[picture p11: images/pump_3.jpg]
555 泵电机与支架
| 7 | <br><br> | 555 泵 ×2 | 电机 Ø、总长、泵头宽、**L 支架:孔距/孔径/板厚/孔到泵轴高度**、进排气嘴朝向、两台是否同款 | Ø38_ 总长：86，泵头宽：_40__ / 纵向孔距（前后距）:_28_, 横向孔距（左右距）：__48_，_ Ø_5, 板厚 _2__ / _孔到泵轴高度 28__,朝侧面水平出气（非朝天）_ |
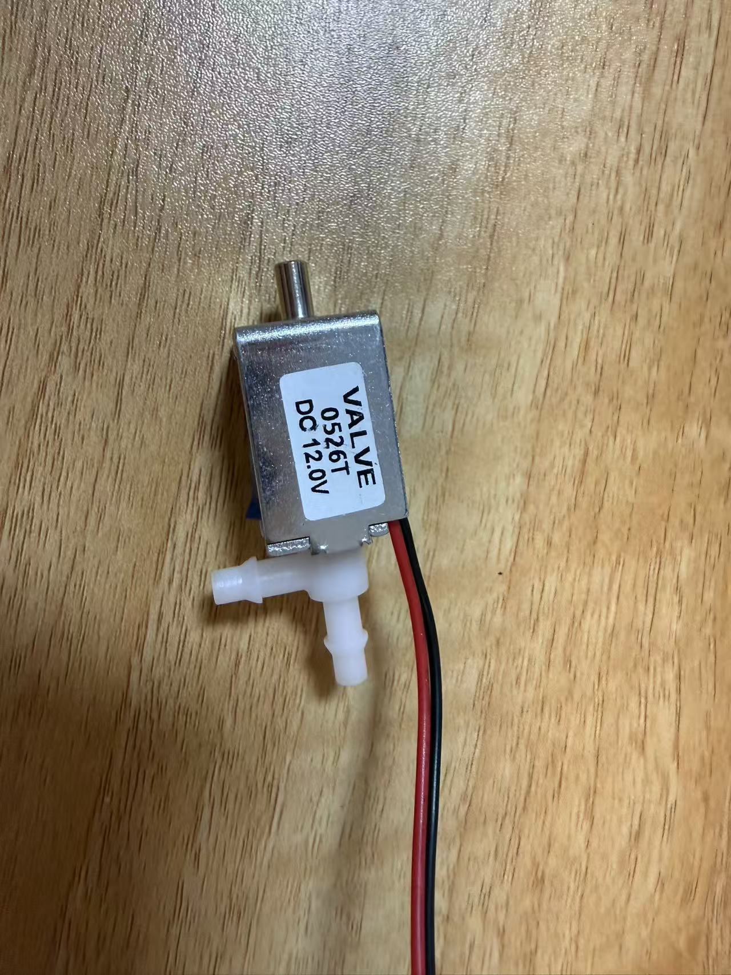
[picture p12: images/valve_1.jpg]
0520B 阀外观
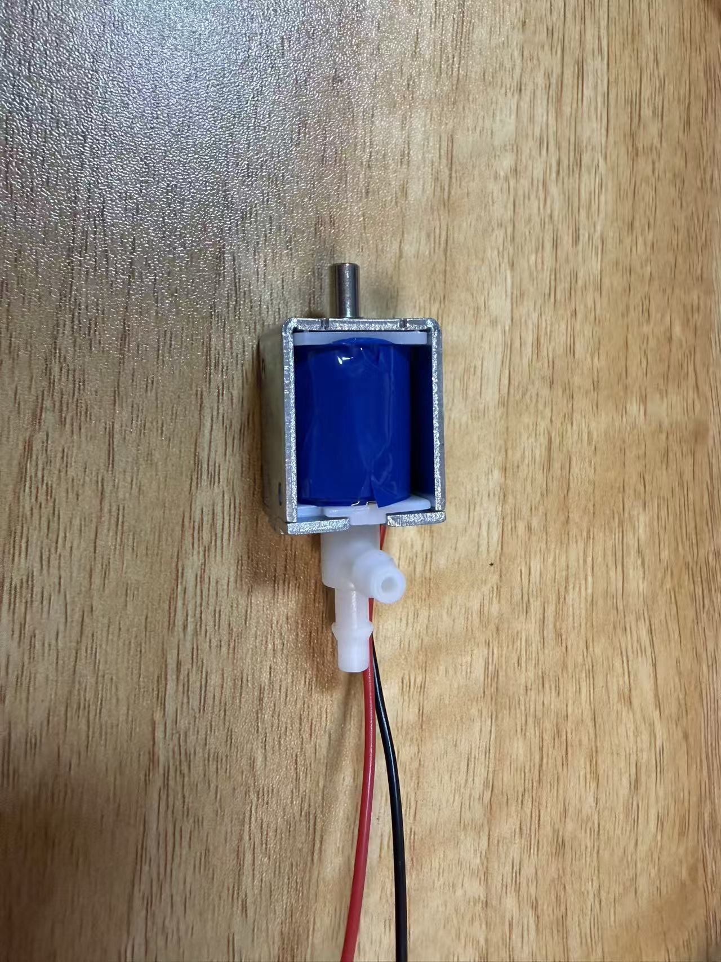
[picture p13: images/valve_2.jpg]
0520B 阀内部与接口
| 8 | <br> | 0520B 阀 | 本体长×宽×高、线圈 Ø、**有无底部安装孔**、进/出/排气口各在哪面+嘴外径 | __25__×__20__×__16__ / _17，无底部安装孔_，顶面1金属嘴(Ø4)，底面1垂直塑料嘴(Ø6)+1侧向塑料嘴(Ø6)__ |
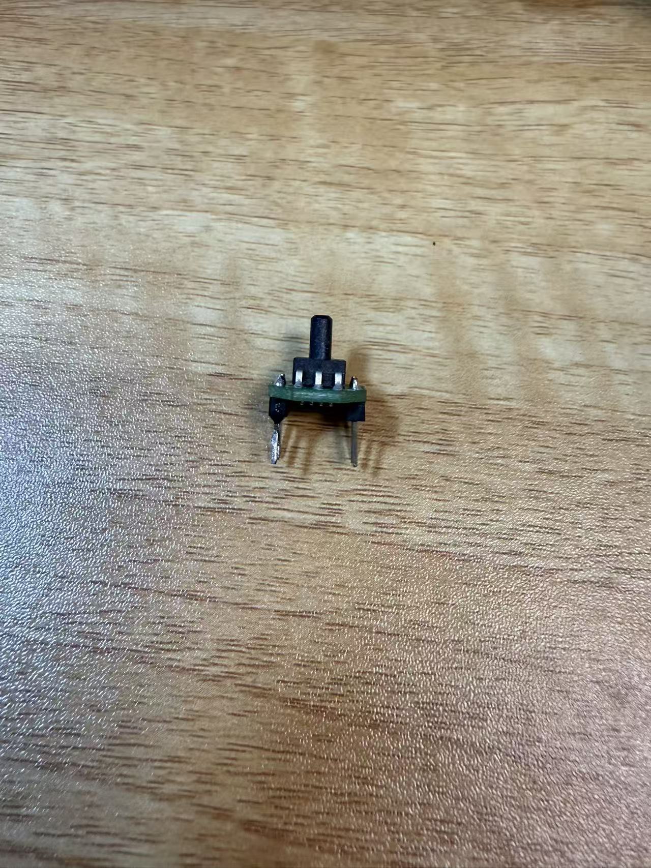
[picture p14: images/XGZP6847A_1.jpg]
XGZP6847A 侧面
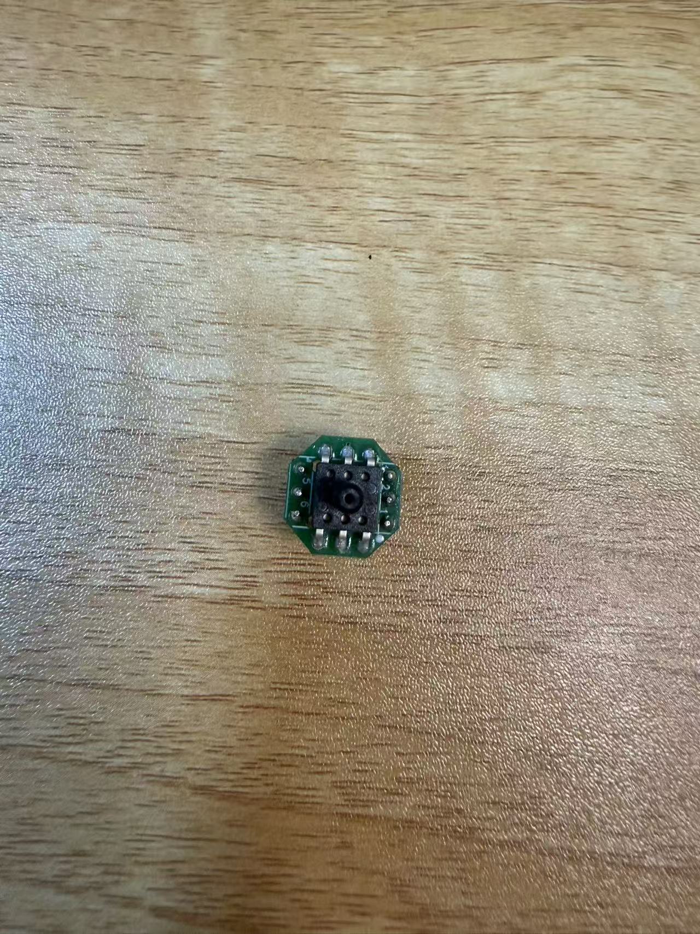
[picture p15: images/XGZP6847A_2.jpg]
XGZP6847A 顶面
| 9 | <br> | XGZP6847A ×7 | 外形长×宽×高、取压嘴外径/朝向、出线方向、7 只是否一致 | __19__×_19___×__12 （高度不含针脚）__ / Ø_3__气嘴垂直向上_排针垂直向下 _ 一致 |
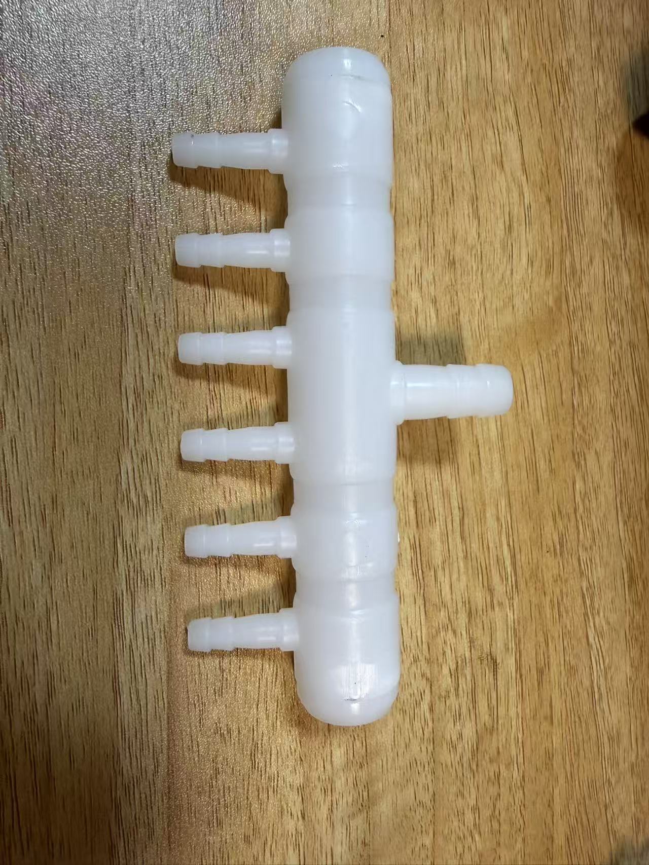
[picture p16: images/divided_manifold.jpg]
真空歧管
| 10 |  | 歧管 | 总长、出口间距、进/出嘴外径、有无安装耳(耳孔距) | _115(主干外径Ø20)___ / _出口间距17___ / 进口外径Ø10，出口外径Ø6____ / __无安装耳__ |
| 11 | —（暂未到货） | 储气罐(到货后) | 外径 Ø、长、嘴位置/外径、**安装耳孔距**、称重 |  暂时不用 |
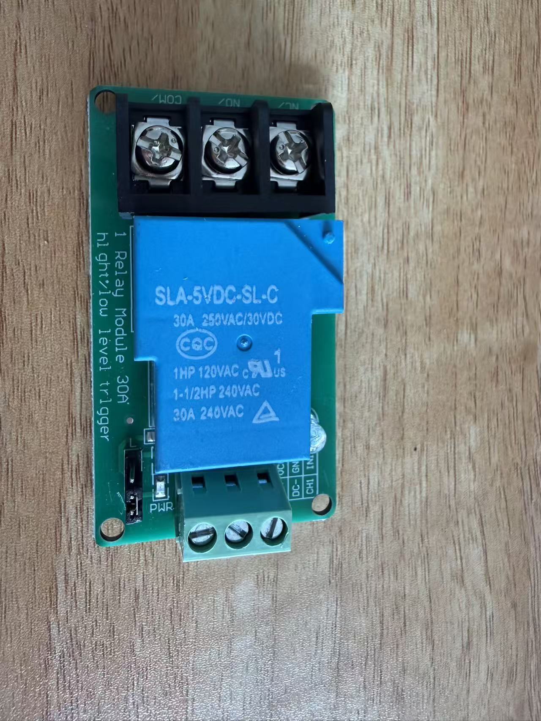
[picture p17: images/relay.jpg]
30A 继电器模块
| 12 |  | 继电器模块| 板长×宽、4 孔孔距×孔径、大电流端子朝向 | __72__×__40__ / _66.5___×__34.5__ Ø_3___ |
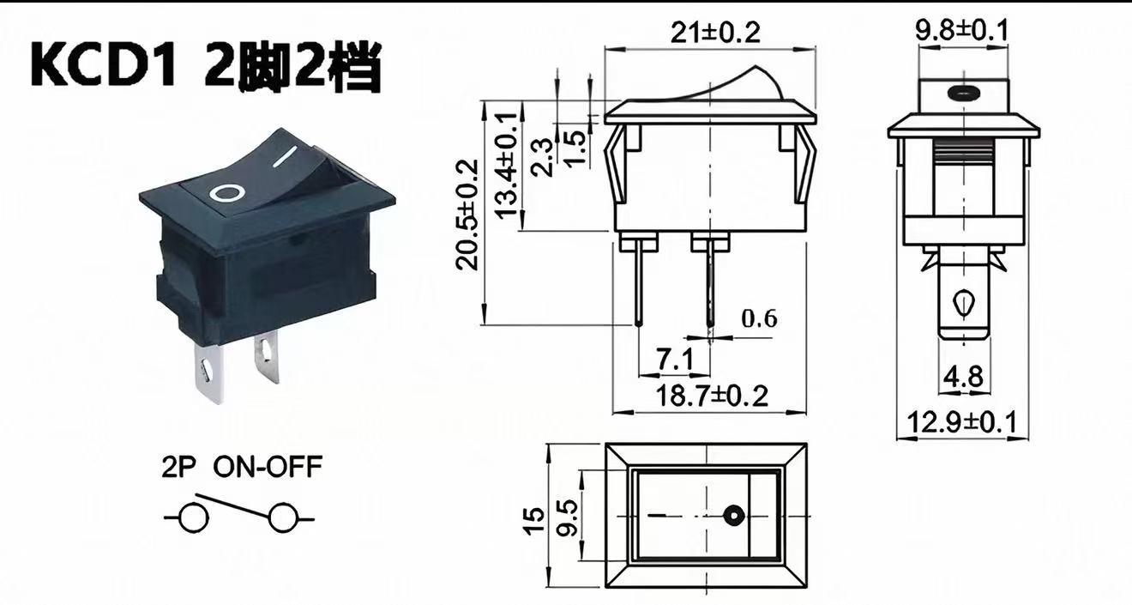
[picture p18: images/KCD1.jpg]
KCD1 船型开关尺寸图
| 13 |  | 总开关(KCD1) | 面板开孔长×宽、卡扣能否吃住 3mm 板 | 矩形 _19.0_×_13.0_ (本体18.7×12.9) / _卡扣式(建议打印件孔位四周减薄至1.5~2mm)_ |
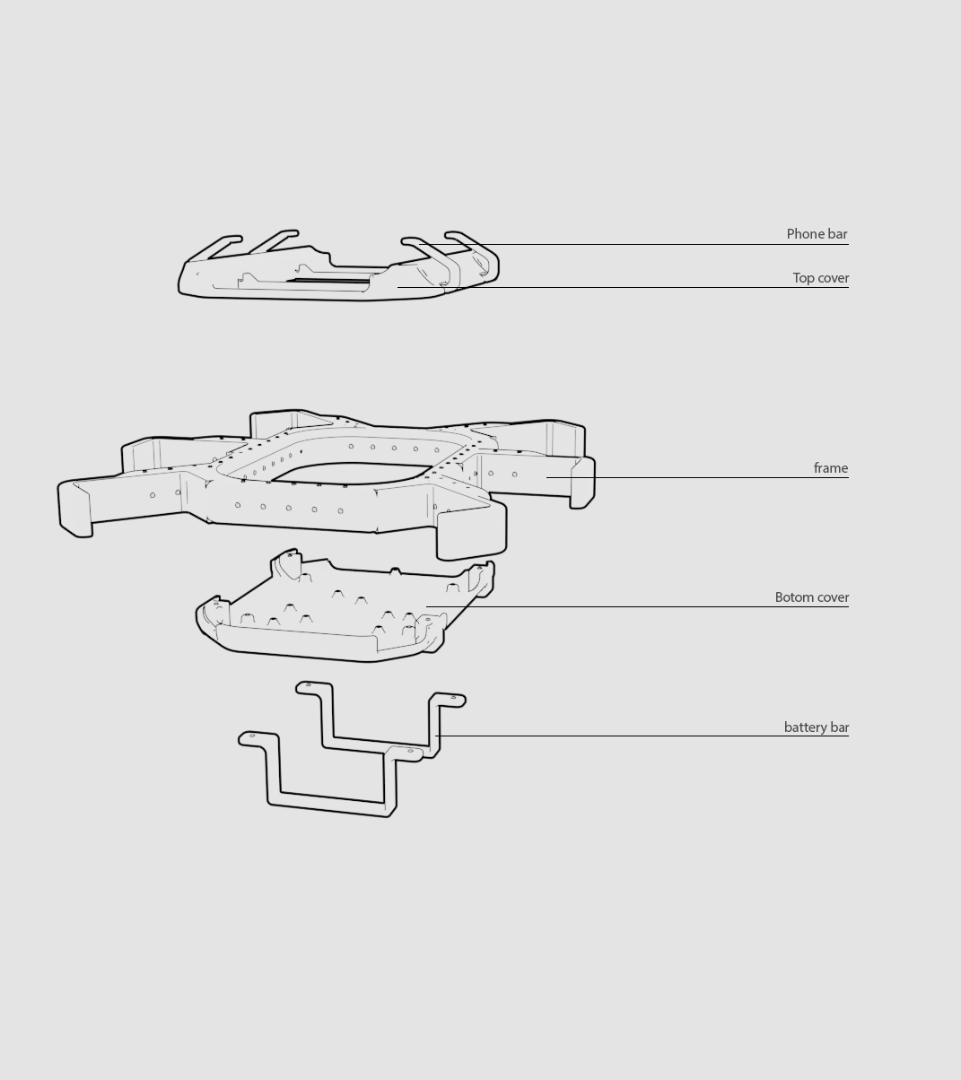
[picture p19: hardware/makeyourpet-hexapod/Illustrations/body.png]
frame 与 top cover 装配示意
| 14 | <br>尚未打印，无实物图 | frame 顶面 | top-cover4 接口形式(卡扣槽位置/螺丝孔位)、顶面可用净空长×宽(到 coxa 舵机线夹)、中央开口尺寸 | 4 个沉头自攻螺钉孔，无卡扣；孔心坐标相对中心为 (±44, ±40)mm，孔距 88×80mm；top-cover4 外廓/直接替换接口 100×140mm；frame 中央最小通孔 76×116mm、约 R18 圆角，顶口因圆角扩至约 81.4×121.4mm；frame 总外廓 198×205.4mm。向外扩展至 coxa 线束前的动态净空仍待整机装配复核。 |
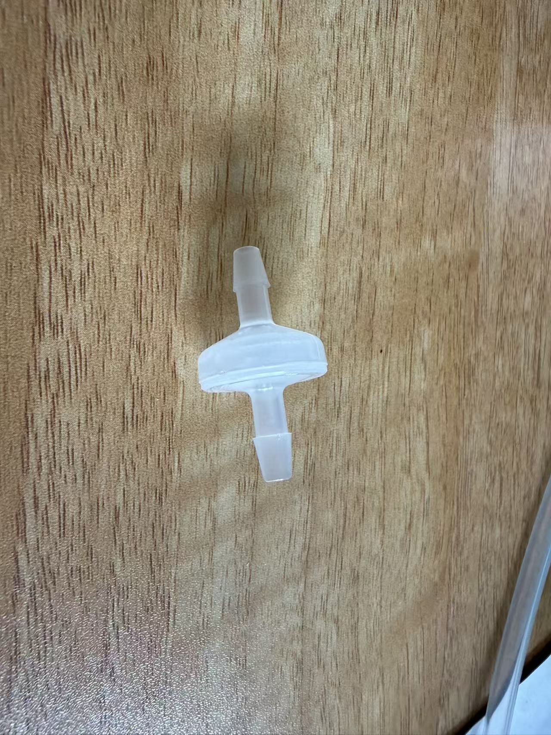
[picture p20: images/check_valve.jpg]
单向阀
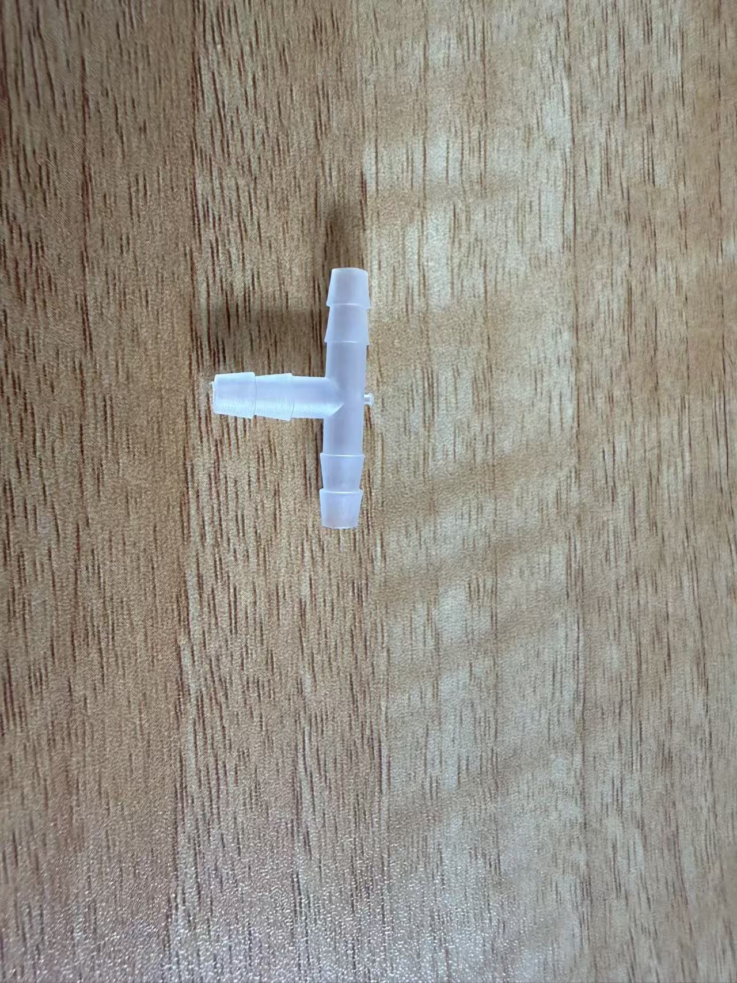
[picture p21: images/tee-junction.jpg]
三通
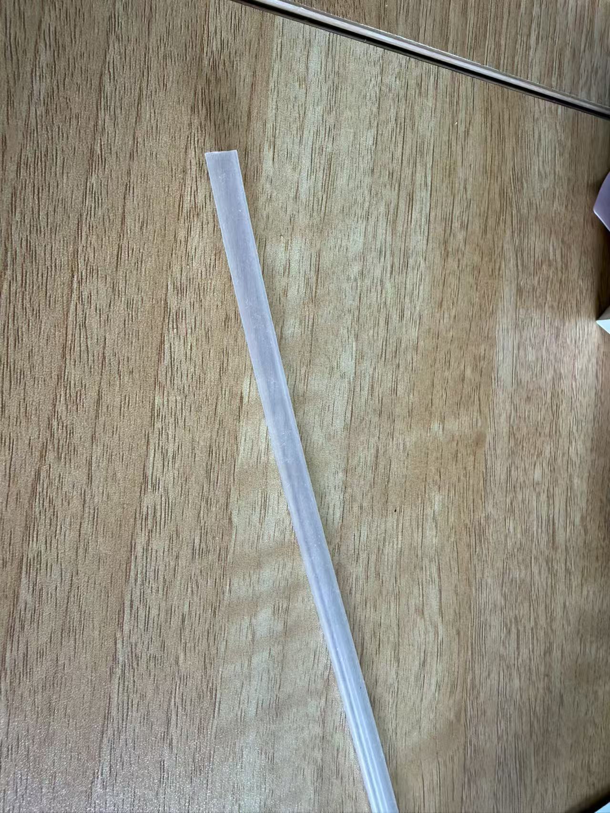
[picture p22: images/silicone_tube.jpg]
硅胶管
| 15 | <br><br> | 单向阀/三通/硅胶管 | 单向阀外径×长、三通外径、管外径(标称 4×6)复核 | __单向阀外径×长：20x35_三通外径 5 _管外径 4x6 |

共 **15 项**。当前只剩 §4-11 储气罐尺寸和 §4-14 到 coxa 线夹的动态
净空不能由已有照片/STL 确认；后者已经转化为 V0 外廓模板试装项。

---

## 5. V0 生成器与交付

### 5.1 本版修正

| 原问题 | V0 处理 |
|---|---|
| 110×95 夹层放不下三块顶面 PCB | 改为 184×108 双面电气甲板,六柱支撑 |
| MOSFET 四孔不是对称矩形 | 按左下角四个实测坐标逐孔生成,不再用 `hx/hy` 猜孔距 |
| 泵支架实测 Ø5、48×28 四孔,旧方案写成 2×M3 | 改为独立适配板 4×Ø5.4,使用 4×M4+大垫圈+3mm TPU 垫 |
| 190×130 外扩后无法从裸 STL 得到 coxa 线束动态净空 | 单独生成 1mm 试装模板,模板通过前不打印正式底板、不钻新增孔 |
| 储气罐和 XT60 板式接口尺寸仍未知 | V0 不生成罐抱箍；XT60 改为扎带槽,避免假精确卡槽 |
| 一体底板改一个孔就要整件重打 | 底板改 M3 模块孔阵列,泵/阀/传感器/歧管均为独立可换件 |

### 5.2 生成与验证

```bash
venv/bin/python tools/generate_p4_bay_v0.py
```

脚本输出 13 个 STL 和 `layout-report.json`。生成时逐件检查水密、有限顶点、
正体积；电气甲板还会检查器件是否越界、任意两个安装孔是否过近。当前
13/13 均通过。原有 `tools/generate_climbing_parts.py` 及旧 STL 不会被重写。

### 5.3 V0 打印清单

| STL | 数量 | 材料/用途 |
|---|---:|---|
| p4-bay-fit-template-v0 | 1 | PLA/PETG,**第一件打印** |
| p4-bay-baseplate-v0 | 1 | PETG,模板确认后再打 |
| p4-bay-electrical-deck-v0 | 1 | PETG |
| p4-bay-deck-post-90mm-v0 | 6 | PETG 试装；正式优先采购 M3×90 六角柱/组合柱 |
| p4-bay-spacer-m25-6mm-v0 | 4 | Pi 5 |
| p4-bay-spacer-m3-6mm-v0 | 按需约 20 | 其余 PCB |
| p4-bay-pump-adapter-v0 | 1 | PETG,V0 单泵 |
| p4-bay-pump-pad-tpu-v0 | 1 | TPU 95A |
| p4-bay-valve-rail-v0 | 1 | PETG+2.5mm 扎带 ×6 |
| p4-bay-sensor-block-v0 | 1 | PLA/PETG,4+3 双排 |
| p4-bay-manifold-clip-v0 | 2 | PETG |
| p4-bay-switch-bracket-v0 | 1 | PETG |
| p4-bay-cable-comb-v0 | 4 | 功率/模拟分开 |

### 5.4 首件实施顺序

1. 打 `p4-bay-fit-template-v0.stl`,装到已经装好 coxa 舵机和线夹的 frame；
   六条腿全行程慢速摆动,确认模板与线束/舵机无干涉。
2. 只用原 `(±44,±40)` 四孔固定模板。需要增强且确认落点为实心后,才在
   `(±44,0)` 钻 Ø2.8mm 底孔；此步骤不可从 STL 静态尺寸替代。
3. 分别打印泵适配板、阀轨、传感器座和歧管卡,拿实物逐件试插。卡位目标
   是可手装、无明显摇晃；不要靠螺丝强压尺寸不合的器件。
4. 打电气甲板,先不通电装全部 PCB,检查底面元件、端子和线弯是否互碰；
   Pi 用 M2.5,其余板用 M3,全部加 6mm 隔柱。
5. 前四步通过后再打正式底板并整舱装配称重。记录到 `docs/weight-log.md`,
   V0 先装单泵；是否加第二泵由真空建立时间和整机重量共同决定。

---

## 6. V1：按装配与连线审核修正版

V0 的 13 个 STL 单件网格虽然有效，但整舱审核发现开口凸筋与泵/阀/传感器
占位冲突、模块孔位不能形成完整紧固、下向针脚/阀嘴被遮挡，以及电气甲板
端子侧没有足够的插拔和弯线空间。V1 因此另建目录和生成器，**不覆盖 V0**。

### 6.1 结构与布线修正

| 审核问题 | V1 修正 |
|---|---|
| V0 只有一个泵位 | 左右两个 64 × 54 mm 共用适配板，中心 `(±46,24)`；右件旋转 180° |
| 开口凸筋侵占器件 | 正式底板改为 4 mm 平板；只保留三条与底板齐平的传感器桥承载梁 |
| 7 个传感器针脚下方不通 | 采用抬高桥，2+2+2+1 排布，桥板底面装配高度 16 mm，每只传感器有独立窗口 |
| 阀底嘴和侧嘴受阻 | 六阀竖装，底嘴向下、侧嘴朝 `-Y`；支撑只接触本体两侧 |
| 歧管卡与传感器桥相撞 | 卡座移到阀轨后侧，歧管轴线约 `(0,-49.5,65)` |
| V0 电气甲板闭口槽无法穿成品接头 | 改为三个开放至板边的缺口，并为所有螺钉端子保留 10–20 mm 服务区 |
| 功率/模拟线容易交叉 | 左侧两只 comb 专走 GPIO/传感器，右侧两只专走电池/泵/阀功率线 |
| V0 的 90 mm 夹层余量不足 | 支柱增至 100 mm；甲板装配高度为 `Z=104…107 mm` |
| 旧方案加入未确认的中间 frame 孔 | V1 只使用已确认的 `(±44,±40)` 四个车架孔 |

电气甲板顶面为分压汇接板、Pi 5、5 V 降压板；底面为继电器、
YYNMOS-8 和两块 XL6009。具体坐标、旋转、端口朝向、10 个线弯服务区以及
各孔绝对坐标见 `hardware/climbing-parts/p4-bay-v1/layout-report.json`。

### 6.2 生成与独立验证

```bash
venv/bin/python tools/generate_p4_bay_v1.py
venv/bin/python tools/validate_p4_bay_v1.py
```

当前结果为 **22 passed, 0 failed**：13 个 STL 全部水密且为单连通体；21 个
已定位打印件实例无正体积碰撞；41 条螺钉路径贯通；7 块 PCB 的边界/同面
间距和 10 个端子服务区通过；7 个传感器针脚、6 个阀底嘴的下向路径通过。
完整打印清单、装配方向和接线分区见
`hardware/climbing-parts/p4-bay-v1/README.md`。
可旋转、筛选并逐件查看坐标的装配示意页见
`html/p4-bay-v1-assembly.html`；其中真实器件使用包络代理，打印 STL 外形未被
伪装为器件精确 CAD。

### 6.3 校验边界

V1 仍不能绕过实物首件：必须先打印 fit template 做六腿全行程动态扫掠，
再复核 555 泵体相对支架孔中心的前后偏置、0520B 塑料嘴实际伸出量和打印
孔径公差。储气罐抱箍继续等实物耳距后再设计。

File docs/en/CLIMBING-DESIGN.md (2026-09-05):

> English translation of [`docs/CLIMBING-DESIGN.md`](../CLIMBING-DESIGN.md). The Chinese original is the maintained source; if they differ, the Chinese version wins.

# Wall-climbing design rationale

## 1. Picking an adhesion method

| Method | Principle | Suitable walls | DIY feasibility | Verdict |
|---|---|---|---|---|
| **Vacuum suction cups + valve bank** | Pump pulls vacuum, one valve per foot controls attach/release | Glass, tile, painted steel, acrylic | ★★★★☆ all standard pneumatic parts | **Main line** |
| EDF pressing against the wall | Ducted fan presses the machine onto the wall | Almost any flat wall | ★★★★☆ off-the-shelf RC parts | Dropped: only works for platforms <800 g, incompatible with a 2 kg platform (see §3) |
| Microspine | Fine needles hook onto microscopic asperities of a rough surface | Brick, concrete, rough paint | ★★★☆☆ needles + printed parts is all it takes, but carrying load on spines alone needs a finely tuned compliant suspension | Dropped: only practical when paired with an EDF |
| Magnetic | Electromagnet / permanent magnet | Steel surfaces only | ★★★★★ | Too narrow a use case, dropped |
| Electrostatic adhesion | High-voltage electrodes polarize the wall | Many | ★☆☆☆☆ high voltage + weak force | Research grade, dropped |
| Biomimetic dry adhesive (gecko) | Van der Waals force | Smooth surfaces | ★☆☆☆☆ hard to make the material yourself, fouls easily | Research grade, dropped |
| Hot-melt glue feet | Glue on, heat to release | Many | ★★☆☆☆ slow cycle, high power | Dropped |

### Leg count: why six legs and not four

Four legs would save 6 servos + 2 foot modules (about −450 g / −¥300–500), but on a wall it is strictly more dangerous:
in swing phase a hexapod has 5 feet attached, a quadruped 3; after a single cup lets go (P2 acceptance already allows a 5% failure rate, so it will happen)
the hexapod still has 4 feet and can gracefully degrade and re-attach, while the quadruped has 2 feet taking a dynamic shock load and will most likely cascade into a fall.
On top of that a quadruped's per-foot peak load is ×1.5 (cups would have to go up to 40 mm, eating the weight advantage), its static gait on the floor has to shift the CG,
and the floor-to-wall transition only ever has "2+2" support. The academic precedent (Hirose's NINJA-I, a quadruped suction-cup wall climber) relies on research-grade
special valves and high-DOF legs, which does not suit DIY.
**Decision: six legs. Reversible fallback: the official configuration has MODE_QUADRUPED, so adding a quadruped gait to the gait engine lets us
A/B test on the same hardware; if P4 gets stuck on weight, pulling the two middle legs and going quadruped is an experiment we can run at any time.**

## 2. Force budget for the suction-cup foot design

Taking the MakeYourPet large platform + adhesion system as a whole robot at **m = 2.5 kg** (upper bound with margin):

- One 30 mm cup (with a 3D-printed anti-deformation shell) at a working vacuum of −50 kPa, measured:
  normal pull-off force = **25 N (2.5 kg)**, shear pull-off on vertical glass = **15 N (1.5 kg)** (about 60% of normal).
- At any moment in the climbing gait at least **5 cups are attached**; being extremely conservative, assume only 3 actually carry load:
  total normal pull ≥ 75 N, giving a **normal safety factor of 3.0** against 2.5 kg (25 N) of gravity;
  total shear pull ≥ 45 N, giving a **shear safety factor of 1.8** against 2.5 kg (25 N) (if all 5 are effective the shear safety factor reaches 3.0 — plenty of margin!).
- Peel moment: with the CG standing off the wall by d, the upper row of cups sees an extra pull of ≈ m·g·d/h (h = spacing between upper and lower feet).
  Every 1 cm you take off d is real margin → **keep the body as close to the wall as possible in the climbing pose, and mount heavy items such as the battery on the wall side**.

System conclusions:
1. 30 mm cups ×6 at −50 kPa works for a whole robot up to 2.5 kg; switch to 40 mm (area ×1.78) for the payload stage.
2. The pump only has to keep the vacuum tank down; the valves handle attach/release per foot → the pump can run intermittently and save power.
3. **NC valves + check valves** make the powered-off state = all feet locked on. This is the single most important passive-safety feature.

## 3. Record of a dropped route: EDF wall pressing

The common DIY approach for rough walls (brick, concrete, latex paint) is a ducted fan pressing the machine onto the wall + friction/microspine feet.
Reason for dropping it (physics vetoed it once the platform was fixed as the MakeYourPet large platform): a 70 mm 12-blade EDF at 4S gives only
12–18 N static thrust; with a friction coefficient μ≈0.6, not slipping needs F_press ≥ m·g/μ, so a 2 kg robot needs 33 N+ of continuous pressing force,
which means dual 90 mm EDFs, hundreds of watts, and it falls the moment the fan stops — in conflict with the project goals of "hangs statically, can carry a payload".
This route only works for lightweight platforms under 800 g (references: the GECO and IJERT papers in §7).
**Conclusion: this project only targets smooth walls (glass/tile/painted steel). Rough walls are out of scope.**

## 4. Pneumatic diagram

```
pump (555 ×2 parallel) → check valve → tank (PET bottle) ─────────┬→ NC 3/2-way valve #1 → foot 1 cup
      ↑                                  │ (XGZP6847A pressure    ├→ NC 3/2-way valve #2 → foot 2 cup
  MOSFET board ← Pi5 GPIO                │ feedback, via          ├→ ...
             Pi5 I2C ← ADS1115 ──────────┘ ADS1115)               └→ NC 3/2-way valve #6 → foot 6 cup
   third port of the 3/2-way valve = atmosphere (energizing switches it to the vent position, releasing that foot)
```

Control logic (adhesion state machine, one per foot):
`RELEASED → press onto the wall → valve to the suction position → wait for pressure ≤ -30kPa (on a 500ms timeout, lift the foot and retry) → ATTACHED (load bearing allowed) → when a move is needed, valve to the vent position → 300ms delay → RELEASED`

Gait constraint: **at least 5 feet ATTACHED at any moment**, and no two adjacent feet released at the same time.

> [!TIP]
> **The killer valve hookup that holds pressure with the power off (P1 stage summary)**
> Measured behavior of the 0520B-type NC 3/2-way valve we bought: with the coil off, port 1 connects to port 3 and port 2 is blocked.
> To get the passive-safety design "power off = cup keeps its vacuum", **you must wire it like this**:
> 1. Port 1 ➡️ to the suction cup
> 2. Port 3 ➡️ to the vacuum pump inlet
> 3. Port 2 ➡️ open to atmosphere
> **Why it works**: with the power off (1 connected to 3) the cup is connected to the stopped vacuum pump, and the check valves inside the diaphragm pump dead-lock the vacuum in. With the power on (1 connected to 2) the cup is opened to atmosphere, pressure is released and the leg can lift. This hookup not only gives absolute power-off anti-fall safety, it also draws 0 current from the solenoid valve while sitting attached. The code must be configured with `VALVE_ON_LEVEL=0`.

## 5. Evolution of the electrical architecture

**Single-brain architecture: the Raspberry Pi 5 is the brain from day one** (`software/` in-house software, the same code stack through all stages):

```
2S battery ─┬─ 7.4V direct → Servo2040 servo power rail (via relay) → 18 servos
            ├─ 5V/5A buck → Pi 5 (USB-C, its own supply, never shared with the servo rail)
            └─ XL6009 boost to 12V → MOSFET board → 6 valves + 2 pumps
Pi 5 ─USB──→ Servo2040 (chica serial protocol: 18 servos + 6 foot contact switches + voltage/current)
Pi 5 ─I2C──→ ADS1115 ×2 → XGZP6847A pressure sensors (from P1)
Pi 5 ─GPIO─→ MOSFET board (valve/pump switching, from P1); GPIO17 → servo relay (from P4)
Pi 5 ─CSI──→ camera module (P5, FPV)
```

- The protocol description and driver implementation are in `software/hexapod/driver.py` (verified byte by byte against the firmware source).
- Before the gait moves a step, the adhesion state machine confirms "the target foot is attached" (`software/hexapod/adhesion.py`).
- **A low-voltage alarm is mandatory**: LiPo undervoltage = pump stops = adhesion decays = fall. In software, `check_power()` throws and stops the machine below 6.0 V (the valves are NC, so it stays attached even with the power off).

## 6. Workspace analysis: can a 3DOF leg get onto a vertical wall

The analysis script is `tools/workspace_analysis.py` (computed with the real link lengths 43/80/120 mm — tibia is the L1 measured value,
see LEG-GEOMETRY-OPEN §2.11 — and the servos' electrical travel, femur −40.3° to +139.7° (L1 measured attach 49.7°,
§2.12) and knee interior angle 0°–176.4°; a 2D leg-plane model, conservative. Recomputed 2026-07-17 against the measured calibration;
**2026-07-18 the cup axis model was corrected**: the physical cup axis runs along the square shaft = a_t − 22.7°, which is not the direction of the K→P line
a_t (a fixed geometric offset, the knee axis K sitting 46.5 mm off the square shaft, LEG-GEOMETRY-OPEN §2.13); the table below has been recomputed on that basis).
The fundamental limit of a 3DOF leg: **foot position and cup orientation are coupled** — pick a foothold and the cup axis is determined,
so all you have to fall back on is the angular compliance of the bellows cup.

**A. Walking on the wall: feasible.** With the body parallel to the wall the kinematics are equivalent to floor walking; the only new constraint is
the cup axis's tilt relative to the wall normal (a bellows cup tolerates about 15°):

| Stand height (body off the wall) | Stance-phase reach | Stride | Cup axis tilt |
|---|---|---|---|
| 90mm | **170mm** | 0 / 30 / 40 / 60mm | 1.6° / ≤8.9° / ≤11.5° / ≤17.2° |
| 90mm | 130mm (floor default) | 0mm | **16.7°, over tolerance** |
| 70mm | 170mm | 0 / 30 / 40mm | 5.0° / ≤11.5° / ≤13.9° |

→ The climbing gait uses **stand height 90 mm + stance reach 170 mm + stride ≤40 mm** (tilt ≤11.5°).
The key change (2026-07-18): **you cannot carry the floor pose of reach=130 onto the wall** — that would put the cup onto the wall at a
16.7° angle; on the wall the feet have to splay out to reach≈170. "Body close to the wall" (lowering the peel moment) and
"cup squared up" pull in opposite directions; 90 mm is still the balance point.

**B. Floor-to-wall transition (front feet onto the wall): kinematically solvable.** Reachable foothold band for a front leg (15° tilt tolerance,
height range relative to the front hip, mm):

| Body pitch | Wall distance from front hip 100 | 140 | 180 |
|---|---|---|---|
| 0° (body level) | +75–+143 | +95–+153 | +95–+141 |
| 30° (nose up about the rear hips) | +96–+168 | +116–+174 | +114–+158 |

→ With the cup axis corrected the reachable band is actually **wider and higher** (about 50–70 mm tall, shifted up overall): with the body level,
feasible footholds exist at every wall distance from 80–200 mm; pitching the body 30° (`robot.py`'s `body_rpy` already supports it)
makes it wider still. Every step of the transition sequence has a solution, but sequencing it is complex, so per the roadmap it stays in P5.

**Conclusions and design decisions:**
1. No need to add a 4th ankle servo to each leg — saves the weight and complexity of 6 servos.
2. The key parameter for feasibility is the bellows cup's real angular tolerance. **P1 test-rig measurement: the tilt tolerance reached 15°!** That means we can unleash the robot's full mobility and climb with a **40 mm stride**, with no need to tighten up to 25 mm.
3. All of the above is computed from electrical travel and does not account for structural interference (femur hitting the body, tibia hitting the femur) — during the P2
   single-leg tests, measure each joint's real mechanical travel and fill it back into this analysis.

## 7. Reference projects and literature

- MakeYourPet hexapod (`hardware/makeyourpet-hexapod/` in this repo, MIT): https://github.com/MakeYourPet/hexapod
- Aecert Robotics hexapod (full Arduino tutorial series): https://aecertrobotics.com , code at https://github.com/Ryan-Mirch/Aecerts_Hexapod_V1
- GECO wall-climbing robot (Ghent University, EDF suction, reference for the dropped route in §3): https://www.instructables.com/GECO-Wall-Climbing-Robot/
- Design of a sub-1 kg EDF wall-climbing robot (IJERT, 2026, reference for the dropped route in §3): https://www.ijert.org/design-and-development-of-a-sub-1-kg-wall-climbing-robot-using-electric-ducted-fan-for-vertical-surface-operations-ijertv15is043914
- Review of wall-climbing robot technology (ScienceDirect, 2024): https://www.sciencedirect.com/science/article/pii/S2773186324000781
- Design of a wall-climbing robot with passive suction cups: https://www.researchgate.net/publication/251991762_Design_of_a_wall-climbing_robot_with_passive_suction_cups

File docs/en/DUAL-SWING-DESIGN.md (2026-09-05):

> English translation of [`docs/DUAL-SWING-DESIGN.md`](../DUAL-SWING-DESIGN.md). The Chinese original is the maintained source; if they differ, the Chinese version wins.

# Dual-leg climbing (dual-swing) · upgrade design

Status: **v1 implemented** (decided and implemented the same day, 2026-08-24:
all three points of §9 approved — A form = duty change + engine generalized to
multiple swings, B dual swing forbids sag/weights, C δ ceiling 45 unchanged.
Changes: `gait.CLIMB_DUAL` + nine surgical edits in `climb.py` (§4) + `--dual`
in two scripts + `ab_quant` landing-transfer compatibility; tests 96→111 all
green (zero regression on single swing + 15 dual-swing items), pty smoke test
passed on 5 branches (mutual-exclusion refusal ×2 / 28 lifts in continuous
walking all in ring order and always exactly 2 airborne at any instant / pair
step / body_lean pair lift). Implementation notes in §10. **To do: §8.3–8.5,
the on-machine ladder** — dual swing on a glass plate on the floor →
re-calibrate the three δ_pair groups (protocol §8.1) → A/B on the wall
(protocol §8.2).)
Measured basis: real-machine window-duration decomposition
`software/logs_analysis/climb_20260819_184038.log`
(08-19 on the wall, long-stride straight walking, 10 lift-land cycles);
zero-force handover, three-group δ calibration
`html/en/handover-delta-calib-20260824.html` (δ*≈28–42 per leg, per-leg
stiffness differs by 4×).

---

## 1. Goal and conclusion (one paragraph)

Single-swing climbing (5/6 duty, 5 feet attached at any instant) already runs
smoothly. The dual-swing upgrade = **exactly 2 legs swinging and 4 legs
attached at any instant** (4/6 duty). Gain: at the same stride, travel speed
**ideally ×2.5** (windows per cycle 6→3 × travel per cycle ×1.25); report ×2
conservatively. Cost: support redundancy drops one notch (a leak case falls
onto the design's "extreme conservative" line), **the δ table must be
re-calibrated as a whole for the dual-swing condition** (both the bounce
readings and the steady-state stored energy change), and nine surgical edits to
the engine's "one leg at a time" assumption. Core finding: **no new phase table
is needed** — the CLIMB offsets stay put, duty goes 5/6→4/6, and the
event-driven clock naturally gathers the lifts into "staggered dual swings":
~0.6 s stagger inside a pair, and every pair is opposite-side, different-row
(§2).

## 2. Form: change one duty, the pairing emerges by itself

### 2.1 Mechanism

- Swing window = (1−duty)·T: at duty 4/6 the window is 2 slots long (1.2 s
  nominal) while adjacent window heads are still 1 slot apart (0.6 s) — the
  windows overlap pairwise, so **exactly 2 legs have phase ≥ duty at any
  instant** (a direct corollary of six phases tiling one turn at equal
  spacing).
- The event-driven clock rules are unchanged (the window tail waits for a firm
  seal, the window head waits for the interlock): each leg's real swing
  duration D (≈4.3s, ≈7s with the handover) far exceeds the 1.2s nominal
  window, so the clock repeatedly stalls at a window tail and gathers the
  following window heads into a steady rhythm of "release one pair every D
  seconds, 0.6s apart inside the pair" (walk-through table in Appendix B).
- The lift ring order stays the CLIMB ring (the smaller duty shifts all window
  heads by one slot, so the first leg goes R3→L1, but the ring order is
  unchanged): **L1→R2→L3→R1→L2→R3**. The combinations airborne at the same
  instant roll as (L1,R2)(R2,L3)(L3,R1)(R1,L2)(L2,R3)(R3,L1) — the strong
  pairs (0.6s stagger, D−0.6s of shared flight) are **(L1,R2)(L3,R1)
  (L2,R3)**, with a weak 0.6s cross-pair overlap.
- The existing property of the current window order, "consecutive lifts are
  always diagonal/crossed and in different rows" (a product of the 08-19 lesson
  about lifting two same-side legs in a row), happens to guarantee: **the two
  legs airborne at the same instant are necessarily opposite-side and in
  different rows** ⇒ the front row always keeps ≥1 foot in place (somebody
  carries the peel moment), and the two middle legs (the softest leg chains)
  are never off the wall at the same time. A property designed back then for
  "adjacency in sequence" is reused by dual swing as "compatibility at the same
  instant".
- The semantics of `--leg-order` are automatically upgraded to "it sets the
  simultaneous combinations": under dual swing, a custom order with same-side
  neighbors = **same-side dual swing at the same instant**, whose cost is far
  higher than under single swing — the help text gets a stronger warning.

### 2.2 Alternative form (not recommended): 3 synchronized-pair windows

Make a new phase table (3 offset groups, same phase inside a pair), window =
pair. It needs the stagger inside the pair to be done by hand (vent/pumping/
coils all have to be scheduled) and the behavior at the window-splice
boundaries has to be re-verified, while "the window is a tidier unit of
progress" buys nothing real — the emergent behavior of duty 4/6 + the current
phase table already contains the stagger and the pairing. Dropped.

## 3. Five ledgers

### 3.1 Speed ledger (anchored to measurement)

Real-machine window decomposition (08-19 on the wall, press 20/stand 62/
no-tank, 10 windows, excellent consistency):

| vent | lift | transfer | descend | press | suck+confirm | total | inter-window gap |
|---|---|---|---|---|---|---|---|
| 0.30 | 0.88 | 0.62 | 0.50 | 1.35 | 0.61 | **4.26s** | 0.04s |

Gate/interlock waits were 0 throughout — the pump kept up the whole time, so
**window duration = pure kinematics**.

- Wall clock per cycle: single swing 6D, dual swing 3D (Appendix B) — **time
  ×1/2**;
- Travel per cycle: the clock advances T per cycle, real stance displacement =
  v·T·duty ≤ stride ceiling S ⇒ travel v·T ≤ S/duty, which at S=40 is 48→60mm
  — **travel ×1.25**;
- Together: at δ=0, 1.86→4.65mm/s; at δ≈27 (mean of the new table) the handover
  adds +2.7s per window, 1.14→2.86mm/s — **ideally ×2.5**. Losses: the vent
  stagger guard (§4-5, occasionally +0.3s), recovery in real-tank mode, gate
  waits on the wall — **report ×2 conservatively**.
- Seal-rupture events per meter: 6/48mm → 6/60mm, **−20% per meter** (the
  ratchet source gets sparser).

### 3.2 Support ledger (redundancy drops one notch, needs a nod)

Continuous walking is steady at **4 attached** (single swing: steady 5). Using
the convention of CLIMBING-DESIGN §2 (budget ceiling 2.5kg = 24.5N, shear
15N/cup @ −50kPa; at the operating point −60 to −75 there is actually another
~×1.2-1.5 of margin):

| Case | Single swing (current) | Dual swing |
|---|---|---|
| Normal, all effective | 5×15/24.5 = **3.1** | 4×15/24.5 = **2.4** |
| Conservative (1 fewer effective) | 2.4 | **1.8** (= the original design's "extreme conservative" line) |
| The instant one cup leaks | 4 attached → 2.4 | **3 attached → 1.8** |

- The whole ladder moves down one rung: half of the redundancy bought back when
  we chose "six legs vs four legs" is spent on speed. Acceptable during
  rope-protected experiments; **whether it becomes the normal convention is
  decided by the on-wall A/B data** (§8).
- The fraction of time a single front cup carries the peel moment goes
  33%→67% (there is always one front leg in the air).
- The static load share per stance leg goes mg/5→mg/4 (+25%): the servo holding
  current and the baseline of the "total current drops back after attachment"
  criterion both have to be re-read at +25%; the magnitude of the total current
  is unchanged (it is still the same body weight).
- Leak rescue self-heals well: leak_pause only stops new lifts and the stance
  field, **the two airborne legs still land and attach in real time** — within
  2–3s it is automatically back to 5–6 attached before anything is done about
  it.

### 3.3 Bounce and δ ledger (whole table re-calibrated, method unchanged)

- The catching side goes 5→4 in parallel: at the same residual stored energy,
  the bounce reading and the force step on each stance cup both go ×5/4.
- **Two legs rupturing at the same instant = worst case ×2.5** (double the
  stored energy into 4 legs) — **staggering the vent inside a pair is a hard
  requirement**, and the engine guard keeps consecutive vents ≥0.4s apart
  (§4-5; as a bonus this preserves the video distinguishability of the per-leg
  vent jumps for ab_quant). Note that the stagger cannot rely on the 0.6s
  window-head difference alone: δ differs per leg, and a later-window leg with
  a small δ finishes laying first (e.g. L1:31 vs R2:22, R2 overtakes by 0.3s),
  so an explicit guard is required.
- **δ* (= that leg's stored energy / its own stiffness) does not depend on the
  number of catchers, but the steady-state stored energy does change**: the
  static share goes mg/5→mg/4 and the event rhythm goes 6→3 windows per cycle,
  so δ*_pair is expected to shift up by +10–30% overall, and L1/R1 may approach
  the analytic ceiling of 45 (§9C). The slope (used in protocol §6 to convert
  the correction) also scales ~×5/4 with the number of catchers, so re-take it
  too.
- Calibration follows the 08-24 three-group linear extrapolation, but **the
  three groups are the current table ×0.5/0.75/1.0** (≈16/23/31 steps) rather
  than starting from δ=0 — bare bounce hurts more under dual swing, and linear
  extrapolation never needed a zero point anyway. Steady-state discipline
  unchanged: discard the first round (the cold-start first window has only a
  single swing and shares into 5 stance legs, a different condition from the
  steady-state 4), count round 2 onward.

### 3.4 Pneumatic/electrical ledger (mostly already-closed items)

- The per-foot check valves (installed and accepted 08-17) already physically
  isolate "the second open valve stealing the vacuum" — the prerequisite for
  parallel pumping under dual swing was laid long ago.
- SUCK measures 0.28–0.32s < the 0.6s stagger ⇒ **pumping is naturally near
  serial**, and the instantaneous tank dip is ≈ the single-swing one.
  Exception: a front-leg retry that deepens the draw together with a rear leg
  landing normally can pump in parallel (rare); just watch the tank pressure in
  TLM. Backup = pump B (`PUMP_B_PIN=26` is defined but not driven; the BOM
  pneumatic diagram already draws 555×2 in parallel).
- Coils: during the swing the exhaust position = coil energized, so the
  overlapping segment of a dual swing holds two coils at ~8W continuously
  (single swing ~4W), and the switching edges are naturally ≥0.4s apart — the
  "six coils stepping ~25W at the same instant" pattern that the 08-18 lesson
  was about does not recur.
- Gate (lift_gate −50): the pair that has just landed gets a whole D before the
  next window head for the pump to pull it deep; this step measured zero
  waiting on 08-19; re-check in real-tank mode on the wall.

### 3.5 Workspace ledger

- **The hard startup check δmax ≤ comp_tail − half stride is unchanged as an
  upper bound** (proof in Appendix A: a stance leg eats (sum of the pair's δ)/4
  in each of two windows, and its accumulated total before its own lift is ≤
  δmax, the same bound as single swing). The check formula in climb_walk is
  unchanged to the letter; the comment is updated.
- The VENT stance-field tail goes ×5/4 (at stride 40, 4→5mm):
  `max_straight_step` is parameterized by gait.duty and tightens by ~1mm
  automatically, no change needed.
- `--sag-comp`: the /5 apportioning arithmetic is semantically invalid under
  dual swing (the sag of 2 legs per window has to be compensated together), and
  the handover is the root fix anyway while the A/B discipline is
  one-or-the-other in the first place — **v1 dual swing simply refuses with
  ap.error**.
- `--handover-weights`: ~~refused under v1 dual swing~~ → **supported under
  dual swing from v1.1** (the revision to decision B made the same day, 08-24,
  after single-swing measurements showed the weights clearly improve slip).
  Mechanism: the share = w[5−d] by forward rotation distance d, then
  **normalized in place over the current STANCE set** (`_share_now` recomputes
  it every tick) — during single-swing laying, stance is always 5 and the
  weights sum to 1, bit-for-bit identical to the v1.5 frozen table; under dual
  swing the stance set changes dynamically with the order inside the pair and
  the landing of the previous pair, and the normalization adapts
  automatically. **The presets split by convention** (model in Appendix C,
  objective function = worst single-leg unloading force): dual swing recommends
  **1,1,1,0,0** (= the pair that just landed plus the rear leg of the next
  pair, split three ways: worst single leg 30.8→27.0 (−12%), mean 30.4→24.0
  (−21%)). Two traps: ① copying the single-swing aggressive preset
  0.6/0.25/0.1/0.05/0 over to dual swing pushes the rear leg of the pair above
  uniform sharing (32.9>30.8 — the "mean −21%" is carried entirely by the
  leading leg's 14.9, a fake ledger); ② the "best mean" 0.5,0.5,0,0,0 funnels
  the whole cycle into the last three legs (single leg 57, leading leg 0) —
  **when judging weights for dual swing, only the worst single leg counts**.
  The automatic preset with no value given splits by --dual (in the script
  layer). The rotation guard is unchanged (deviate from the rotation and it
  falls back to uniform sharing; the "stance ≠ 5" check only applies to single
  swing — a swing in flight is by design normal under dual swing). ⚠ Turning
  the weights on changes the steady-state operating point: **run the
  three-group δ_pair calibration with the weights on** (the model expects δ* to
  shift down accordingly, putting the worst leg further from the analytic
  ceiling of 45 — the weights are exactly the first relief when δ*_pair hits
  the cap, ahead of raising the ceiling as in decision C).

## 4. Engine surgery list (the nine places that assume "one leg at a time")

1. **Window membership**: `_slot()` single leg → the set of legs in a window
   (always 2 elements); the window-head decision now fires on **each leg's own
   window-head edge**; `_slot_active/_slot_skipped/_block_t/_gate_t` are stored
   per leg (cleared on window switch → cleared on the head edge).
2. **Clock advance**: adv = min over the legs in a window (not started and not
   skipped = stalls at its window head, 0; started and not back to STANCE =
   advance at most to its window tail; skipped = no constraint).
3. **Interlock/gate**: "the other 5 all attached" → "**every leg not inside a
   swing window** is attached, not leaking, and deeper than the gate" (legs in
   a window are exempt, which naturally covers the leading leg of a pair being
   airborne); the re-check before venting after the laying finishes uses the
   same convention.
4. **Zero-force handover**: `_ho_left` is stored per leg (two handovers may
   overlap); apportioning changes to **recomputing every tick over the current
   STANCE set** (dropping the freeze at start) — the leading leg's frozen table
   would hand δ/5 to the second leg of the pair that has already entered
   HANDOVER, polluting the ledger. Under the single-swing condition the STANCE
   set is constant during a handover ⇒ live computation is bit-for-bit
   identical to freezing, so the regression risk is zero (a test asserts it).
   Out-of-range truncation (_foot_xy_ok every tick) and the leak pause are
   unchanged and take effect per leg.
5. **Vent stagger guard** (new): after the later-window leg finishes laying its
   handover, it must **wait until the earlier-window leg has vented and at
   least 0.4s has passed since the last vent** before request_release; it stays
   sealed while waiting (the completed HANDOVER state), and the wait is exposed
   under the gate_wait convention.
6. **Single step 'i'**: one press = the two legs of the pair (the rotation leg
   + the window-order successor) are accepted one after the other and lifted to
   HOVER (two hovering); the next press = the two land and attach one after the
   other and stop automatically; the rotation advances by 2 in one go; the
   prompt text changes to two legs. `step_hover_leg` returns a set.
7. **Fast-forward to the rotation leg when starting**: align to the rotation
   leg's window head (the formula is generic, unchanged); the successor's
   window head arrives naturally 0.6s later.
8. **Rotation guard** (`_prev_lift`): the successor semantics are unchanged
   (the next leg in window order). From v1.1 dual swing has weights: the guard
   checks as usual (deviate from the rotation → fall back to uniform sharing);
   the rear leg of a pair lifting right after the leading leg is on the
   rotation, so the weights apply as usual. The "stance ≠ 5" check only applies
   to single swing (a swing in flight is by design normal under dual swing).
9. **sag_comp**: refused under dual swing (§3.5); the two places in
   `max_straight_step` that use `/5` and `5.0*comp` are inert at sag=0 and do
   not block dual swing; the comment marks the convention limit.

**What does not change**: the startup sequence (feet are pressed in and pumped
one at a time in series — the reaction-force seating problem has nothing to do
with the gait), adhesion.py's state machine, the exit/retrieve/--release
sequences, the leak watch (per leg; HANDOVER is already handled), the freeze
semantics (all targets are held, equally true with two legs airborne),
`comp_tail`/`_worst_stance_travel`/`_clamp_speed`/`_landing_xy` (parameterized
by duty, they follow automatically).

**Corner cases** (covered by tests): when a front leg's retry drags on, the
clock stalls at its window tail while the rear leg finishes landing in real
time (briefly back to 5 attached) — if the retries are exhausted and it
freezes, 2 legs may be airborne; targets are held and the manual handling is
the same as today; in air mode the count of 2 give-ups per window still runs.

## 5. Gait definition and script interface

- `gait.py`: `DUAL = replace(CLIMB, duty=4/6, name="climb-dual")` (same offset
  set); it composes naturally with `gait_with_slot_order` (the head-order
  formula takes the new duty).
- `climb_walk.py` / `body_lean.py`: a `--dual` switch (default off = current
  single-swing behavior); mutually exclusive with `--sag-comp` (ap.error);
  `--handover-weights` may be on at the same time from v1.1 (with no value, the
  automatic preset splits by convention: single-swing aggressive preset /
  dual-swing 1,1,1,0,0); on startup it prints "dual swing windows: ring order
  L1→R2→L3→R1→L2→R3, steady state always 4 attached, the δ table must be
  calibrated for the dual-swing condition, do not compare A/B across
  conventions"; the black-box parameter line records `dual=1`; the hard δ check
  formula is unchanged.
- `body_lean.py --dual`: **pair lift** in place (request_lift generalized to a
  pair, the number keys pick the leading leg of the pair) — the vehicle for the
  three-group dual-swing δ calibration.
- `runlog.py`: no change needed (events are per leg anyway; PHASE_CH is already
  complete).

## 6. Calibration and A/B (section added to HANDOVER-AB-PROTOCOL)

1. **The time-sync marker discipline, restated**: start the recording first →
   start body_lean → **the §4.3 body-lean marker is mandatory** (the lesson of
   all three 08-24 groups being wrong: activity contrast has no immunity
   against aligning to the cycle rhythm).
2. Three dual-swing δ groups: pair lift in place at the current table
   ×0.5/0.75/1.0, ≥2 rounds per group, discard the first round; ab_quant
   per-leg vent jumps → linear extrapolation to δ*_pair → start calibrated at
   ×0.8.
3. A/B vs single swing (continuous walking at the same parameters): net advance
   rate, rupture events per meter, displacement per event, current ratchet
   slope, worst cup-pressure distribution, gate-wait count.
4. ab_quant check items: parse_log's per-leg state machine must tolerate
   interleaving (run a mock dual-swing log through it); the handover look-back
   window is already per leg; the round index = per-leg ordinal already
   tolerates dropouts; the summary line is labeled with the dual convention.

## 7. Test list (added to tests/test_climb.py, in the existing style)

1. duty 4/6 windows tile fully: at any t exactly 2 legs are in a window; the
   ring order = the CLIMB ring (first leg L1).
2. Mock continuous walking for 2 cycles: start rhythm 0/0.6/D/D+0.6/…, all 12
   lift-land cycles in ring order, pulses resolvable with zero freezes
   throughout.
3. Interlock exemption: at the successor's window head, the leading leg being
   airborne still lets it through; a leg **outside a window** that is not
   attached → lift refused + the timeout freeze names it (the exemption does
   not spread).
4. Vent stagger guard: when the later leg's δ is smaller than the earlier
   one's (the R2:22 vs L1:31 kind), the later leg waits for the earlier leg's
   vent +0.4s; vent order = window-head order.
5. Overlapping handovers sum to zero: with two handovers in flight at once, the
   vector sum of the six legs' displacements is 0 every tick; a stance leg
   receiving two shares has them computed live over the current STANCE set.
6. Single-swing regression: live apportioning is bit-for-bit identical to the
   old frozen table (the existing 96 tests all green + a dedicated assertion).
7. Clock-stall semantics: the clock stalls at the leading leg's window tail
   until it is firmly attached; the later leg finishes landing in real time.
8. Leading leg in FAULT retry, later leg closes out normally; if the retries
   are exhausted and it freezes with two legs airborne, the targets are held.
9. The gate and the pre-vent re-check use the "legs outside a window" set.
10. Single step 'i' pair step: both hover, both land, automatic stop, rotation
    +2.
11. Rotation pair on starting: the first pair from standstill = the rotation
    leg + the successor.
12. δ budget: at δmax=45 the startup check under dual swing has the same bound
    as single swing (the algebraic assertion of Appendix A).
13. `max_straight_step(duty=4/6)`: finite, tightens by ~1mm with duty.
14. `--dual` and sag are mutually exclusive and refused (from v1.1 the weights
    are let through, normalization unchanged); the `--leg-order`+`--dual`
    combination takes effect.
15. Leak rescue: a stance leak during a dual swing → new lifts stop, both
    swings land, rescue/freeze conventions unchanged.
16. Dual-swing weight shares (v1.1): 1,1,1,0,0 lifting L1+R2 — the partner and
    the leading leg of the next pair get 0 throughout, d3/d4/d5 get δ/3 each,
    and after the rear leg unloads and it is normalized, L2/R3 get δ/2 each;
    under overlapping laying the sum is zero every tick and the guard does not
    fire.
17. Dual-swing weight rotation guard (v1.1): lifting the same pair repeatedly,
    from the second time on the leading leg falls back to uniform sharing and
    leaves a trace (a leg whose weight preset is always 0 really does get a
    share under uniform sharing = distinguishable).

## 8. Acceptance (definition of implementation complete)

1. ✅ All tests green (96 existing, zero changes and zero regressions + 15
   dual-swing items = 111, 2026-08-24).
2. ✅ Mock pty smoke test, five branches (2026-08-24): --dual+--sag-comp
   refused with exit 2 / weights without --handover refused with exit 2 (before
   v1.1 this slot was the dual+weights mutual-exclusion refusal) /
   continuous walking, 28 lifts all in ring order + always exactly 2
   airborne + clean exit / pair step i×2 (L1+R2 hover → land together → next
   pair L3+R1) / body_lean pair lift and land end to end (with the δ table).
3. Dual swing on a glass plate on the floor (start from the single-swing δ
   table, watch tank pressure/current/bounce).
4. Re-calibrate the three dual-swing δ groups (§6 / protocol §8.1), δ*_pair
   entered in the table.
5. On-wall A/B (protocol §8.2): net advance ≥1.8× single swing, displacement
   per event and current ratchet no worse than single swing at the same δ level
   — only after passing this do we discuss making it the normal convention
   (§3.2).

## 9. Decisions (2026-08-24, all approved)

- **A. Form**: ✅ "duty 4/6 + the current phase table + the engine generalized
  to multiple swings" (§2.1, the stagger emerges by itself); the alternative of
  3 synchronized-pair windows (§2.2) is dropped.
- **B. v1 scope**: ✅ dual swing forbids `--sag-comp`/`--handover-weights`
  (§3.5; CLI ap.error + a ValueError at the engine entry, double insurance);
  single step 'i' = pair step. **v1.1 revision on 08-24 (driven by the user's
  measurements)**: the weights are partly unbanned — on-wall single-swing
  measurements showed `--handover-weights` clearly improves slip, so dual swing
  is supported via the v1.1 mechanism of §3.5 (value by distance + normalize in
  place) plus the dual-swing-specific preset 1,1,1,0,0; the sag ban is
  unchanged.
- **C. Analytic ceiling for δ**: ✅ 45 unchanged; if δ*_pair breaks through it,
  discuss raising it per the room ledger (at stand 60 / trim 8, comp_tail −
  half stride ≈40) — calibrate first, then change the ledger, do not spend it
  in advance.

## 10. Implementation notes (2026-08-24, off-design issues found and handled during implementation)

1. **Start-alignment deadlock (caught on the machine; ancestor of test §7.8)**:
   besides "all legs STANCE", the original alignment condition also checked
   "no swing in flight" (the old `_slot_active`) — a leg that has just closed
   out its swing is back in STANCE but its window instance is still marked
   active until the window tail, which wastes the rising edge of want_go; when
   a pair step is accepted again on the same tick as the pair closes out, the
   rotation leg's current window has already been marked skipped and it can
   only wait for the next cycle, while its partner lifts to hover first and
   stalls the clock dead = deadlock. Fix: delete the redundant condition — "all
   legs STANCE" already implies "no swing in flight". The same narrow-window
   (1 tick) hazard under single swing is eliminated along with it.
2. **Apportioning table frozen → recomputed every tick** (§4-4 implemented):
   the leading leg's frozen table would hand a share to the second leg of the
   pair that has already entered HANDOVER (ledger pollution); under the
   single-swing condition the STANCE set is constant during laying, so live
   computation is bit-for-bit identical to the old freeze (the 96 existing
   tests all green is the proof). The weights table (single swing only) is
   still frozen at the instant of release, and the rotation-guard semantics are
   unchanged.
3. **δ=0 now goes through the HANDOVER dwell state too**: the queued wait for
   vent staggering needs a "released but not yet vented" dwell phase; at δ=0
   step 4.7 falls straight through to VENT on the same tick, which is
   unobservable between ticks and identical to the old "vent directly"
   behavior (including the pre-vent gate re-check, same tick, same data).
4. **ab_quant landing-transfer compatibility**: the second leg of a pair step
   goes hover→descend through the landing stagger queue (not transfer→descend),
   and the `\w+` in "landing: L1+R2" only captures the first leg — without
   patching the regex that leg would be dropped from the calibration table
   entirely. Added `相位 (\w+) hover→descend` ("phase (\w+) hover→descend"; in
   single-swing logs the two events coexist on the same tick, so whichever
   matches first means the same thing); verified end to end on a dual-swing
   mock log: 22 lift-land cycles in continuous walking, per-leg assembly all
   correct, 21/21 places where adjacent lift-land times overlap with zero
   cross-talk, both legs of every pair entered in the pair-step/pair-lift logs,
   and every leg in the δ table carrying handover events.
5. **Zero change to the stride budget formula**: both the hard startup check
   δmax ≤ comp_tail − half stride and `max_straight_step` are parameterized by
   gait.duty and follow automatically (the vent tail ×5/4 tightens things by
   ~1mm on its own), and the Appendix A upper-bound algebra gives the same
   bound under dual swing (the test asserts it exactly against the 2s/s/0 drift
   profile of the share geometry).
6. **v1.1 unbanning of the weights (08-24, same day, driven by the user's
   single-swing measurements)**: the `_freeze_share` frozen-table mechanism is
   replaced by `_weights_ok` (settled at the instant of release, the guard
   unchanged) + `_share_now` (value by distance every tick + normalize in place
   — under single swing stance is always 5, so it is bit-for-bit identical to
   the frozen table; under dual swing the dynamic set adapts automatically);
   `_lean_room`'s pre-deduction now takes the maximum of the live shares (the
   single-swing convention is unchanged). The Appendix C model fixes the
   preset: the objective function must use the **worst single leg** — the
   best-mean preset (0.5,0.5,0,0,0) funnels the cycle into the last three legs
   (single leg 57), and copying the single-swing aggressive preset pushes the
   rear leg of the pair past uniform sharing (32.9>30.8), while the dual-swing
   preset 1,1,1,0,0 gives −12% on the worst and −21% on the mean. Tests 113
   (+2: exact share assertion / distinguishable rotation-guard fallback); smoke
   tests +3 (single-swing automatic preset regression / dual-swing automatic
   preset / full pair lift-and-land flow with weights).

## Appendix A: the δmax upper bound is unchanged under dual swing (proof)

Between its own two lifts, stance leg i goes through two other windows and eats
a downhill share of (δ_a+δ_b)/4 in each; total eaten = (Σ_{the other four
legs} δ)/4 ≤ 4·δmax/4 = **δmax**. When its own turn to lift comes it first
unloads +δ_i uphill, and on landing it resets to the standing position — so the
maximum extra downhill outswing is ≤ δmax, the same bound as single swing (5
windows × δ/5 ≤ δmax). The property that under a per-leg table the mean
residual is swallowed by the landing reset (HANDOVER-DESIGN §2 ⚠) holds
identically for dual swing: a first-round artifact, and zero drift per round in
steady state.

## Appendix B: steady-state timeline walk-through (D = real duration of one window)

Window heads (clock): L1@0, R2@0.6, L3@1.2, R1@1.8, L2@2.4, R3@3.0; window
length 1.2. Clock rule: it cannot pass the window tail of a leg that is not
firmly attached. After the cold start:

| Real time | Event | Airborne at that instant |
|---|---|---|
| 0 | L1 window head releases (handover→vent→swing) | L1 |
| 0.6 | R2 window head (L1 exempt, inside a window) | L1, R2 |
| 0.6→D | clock stalls at L1's window tail (1.2) waiting for a firm seal | L1, R2 |
| D | L1 firmly attached, clock passes L3's window head | R2, L3 |
| D+0.6 | R2 firmly attached, clock passes R1's window head | L3, R1 |
| 2D | L3 firmly attached, L2 window head | R1, L2 |
| 2D+0.6 | R1 firmly attached, R3 window head | L2, R3 |
| 3D | L2 firmly attached, L1's next-round window head | R3, L1 |

Cycle = **3D** (single swing 6D); steady state is always 2 swinging / 4
attached; the strong pairs (L1,R2)(L3,R1)(L2,R3) are staggered by 0.6s, with a
weak 0.6s cross-pair overlap; the pumping intervals alternate 0.6s / D−0.6s.

## Appendix C: 1-D model of the dual-swing weights (verification script, runs as is; the basis for the v1.1 preset)

The Appendix A spring ledger extended to the dual-swing steady-state timeline
(Appendix B): at the window head of pair (A,B), prevB, the second leg of the
previous pair, is still airborne; A unloads first (for the first 0.6s its
partner B is still supporting and prevB is in the air), and 0.6s later B leaves
and starts unloading while prevB lands; A and B land one after the other (A
into a 4-lock, B into a 5-lock). The share policy is isomorphic to the engine's
`_share_now`: take w[5−d] by forward rotation distance d and normalize in
place.

```python
MG, PH1 = 89.0, 6.0        # mg/k mm (Appendix A convention); amount that can be laid within the window-head difference inside a pair

def share(policy, sup_d):  # sup_d: {leg: forward distance 1..5}
    if policy == "uniform":
        return {n: 1.0 / len(sup_d) for n in sup_d}
    raw = {n: policy[5 - d] for n, d in sup_d.items()}
    t = sum(raw.values())
    return {n: v / t for n, v in raw.items()} if t > 1e-12 else \
        {n: 1.0 / len(sup_d) for n in sup_d}

def land(y, j, att):
    y[j] = sum(y[i] for i in att) / len(att) - MG / len(att)

def sim_dual(policy, cycles=400, u=0.0, tail=6):
    y, peak = [0.0] * 6, {i: -1e9 for i in range(6)}
    for c in range(cycles):
        for A, B in ((0, 1), (2, 3), (4, 5)):
            O = [(A + k) % 6 for k in (2, 3, 4, 5)]
            X = (sum(y[i] for i in [A, B] + O[:3]) - MG) / 5
            fA = y[A] - X
            a1 = min(PH1, max(fA, 0.0))
            for n, s in share(policy, {B: 1, O[0]: 2, O[1]: 3,
                                       O[2]: 4}).items():
                y[n] += a1 * s              # head segment: partner still there, prevB airborne
            land(y, O[3], [A, B] + O[:3])   # prevB lands
            for n, s in share(policy, {O[0]: 2, O[1]: 3, O[2]: 4,
                                       O[3]: 5}).items():
                y[n] += (fA - a1) * s       # tail segment: partner has left
            y[A] -= fA
            Xb = (sum(y[i] for i in [B] + O) - MG) / 5
            fB = y[B] - Xb
            for n, s in share(policy, {O[0]: 1, O[1]: 2, O[2]: 3,
                                       O[3]: 4}).items():
                y[n] += fB * s
            y[B] -= fB
            for i in O:
                y[i] += u / 2               # stance field (u/2 per window)
            land(y, A, O)                   # A into a 4-lock
            land(y, B, [A] + O)             # B into a 5-lock
            if c >= cycles - tail:
                peak[A], peak[B] = max(peak[A], fA), max(peak[B], fB)
    return peak
```

Results (steady-state unloading force in mm, the same for u=0 and u=40; the
single-swing control reproduces Appendix A):

| Preset | Worst single leg | Mean | Per leg (leading/rear leg of a pair) | Verdict |
|---|---|---|---|---|
| Single-swing control: uniform / aggressive | 29.7 / 20.2 | same as left | six legs uniform | reproduces Appendix A ✓ |
| Dual swing · uniform (v1) | **30.8** | 30.4 | 29.9 / 30.8 | baseline (≈ single-swing uniform) |
| Dual swing · single-swing aggressive preset copied over | **32.9** ✗ | 23.9 | 14.9 / 32.9 | fake mean: the rear leg gets pushed higher instead |
| Dual swing · 0.5,0.5,0,0,0 | **57.0** ✗✗ | 22.2 | ≈0 / 57 | best-mean trap: the cycle funnels into the rear leg |
| Dual swing · **1,1,1,0,0** (the preset) | **27.0** | 24.0 | 21.0 / 27.0 | worst −12%, mean −21% |

A grid sweep (w monotonically decreasing × normalization invariance) shows the
whole (a,a,a,0,0) family tied for best under the worst-single-leg objective at
27.0 — i.e. "the pair that just landed plus the rear leg of the next pair,
split three ways; the leg about to lift and its partner get nothing". The model
does not include the leg-chain stiffness differences or the nonlinear loss
layer (the same limitation as Appendix A), so the relative conclusions are
usable while the absolute values wait on the three-group δ_pair measurement.

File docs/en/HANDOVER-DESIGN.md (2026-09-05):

> English translation of [`docs/HANDOVER-DESIGN.md`](../HANDOVER-DESIGN.md). The Chinese original is the maintained source; if they differ, the Chinese version wins.

# Zero-force handover before vent · implementation design

Status: **implemented** (design frozen 2026-08-20 and implemented the same day:
`hexapod/climb.py` update() step 4.7 + `LegConfig.handover_mm` + `--handover` in
both scripts; all 8 items of the §7 test list + the mock smoke test pass.
Added during implementation, outside the design: CLIMB_COLOR in
`scripts/sim_walk.py` also picks its color by phase, so the HANDOVER key was
added there too — the same family of KeyError hazard as PHASE_CH in §3.2,
missed by the design.
**To do: the §9.3 on-robot A/B acceptance** — the experiment plan and the
quantification tool are ready:
`docs/en/HANDOVER-AB-PROTOCOL.md` + `software/logs_analysis/ab_quant.py`).
2026-08-24, multi-swing generalization (docs/en/DUAL-SWING-DESIGN.md, dual-leg
crawling): `_ho_left` is now stored per leg (two handovers can overlap),
apportionment is now computed live each tick from the current STANCE set
(bit-identical to the old frozen version in the single-swing case), δ=0 also
goes through HANDOVER first (falling straight through to VENT on the same tick,
unobservable between ticks), and venting gained three gates — a window-head
order queue, VENT_STAGGER_S staggering, and a re-check of the gate. The
"one leg at a time, no per-leg storage needed" wording in §3.4/§3.5 below is
archival only; for the current implementation see step 4.7 in climb.py.
Same day, v1.1: the weights (§5 v1.5) were unlocked for dual swing — after the
single-swing measurements showed the weights clearly improve slip, shares are
now "valued by rotation distance, then normalized in place over the current
stance set" (`_share_now`, computed live each tick; with single swing there are
always 5 stance legs, so it is bit-identical to the frozen table), and the
presets are split by convention: dual swing recommends 1,1,1,0,0, and the
aggressive single-swing preset must not be copied over (DUAL-SWING-DESIGN
§3.5 / appendix C model).
Measured basis: `html/en/vent-snap-20260820.html` (quantification report of the
08-20 stepping-in-place experiment),
`software/logs_analysis/lean_20260820_102117.log`, `images/lean_20260820.mp4`.

---

## 1. The problem to solve (one paragraph)
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

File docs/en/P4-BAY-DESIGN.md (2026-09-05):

> English translation of [`docs/P4-BAY-DESIGN.md`](../P4-BAY-DESIGN.md). The Chinese original is the maintained source; if they differ, the Chinese version wins.

# P4 electrical + pneumatic bay mounting parts · design

Goal: pack every electrical/pneumatic part of the P4 adhesion system into **one "bay" that comes off as a unit**,
bolted to the top face of the MakeYourPet body (frame), a few M3 screws and it is off the machine. The dimensions
measured so far have already produced a **V0 trial-fit STL set**; the generator is a standalone `tools/generate_p4_bay_v0.py`,
writing into `hardware/climbing-parts/p4-bay-v0/`. V0 has to pass the 1mm outline template and a trial fit of the
real parts first; it must not go climbing without a real fit check.
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

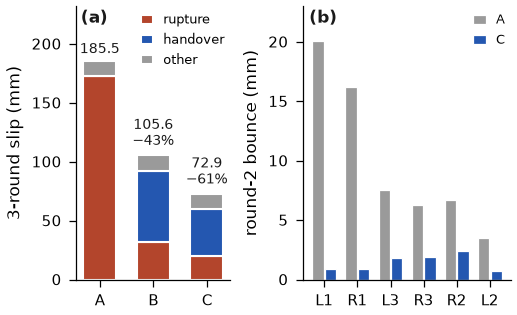
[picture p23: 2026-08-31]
paper/figures/fig_waterfall.png

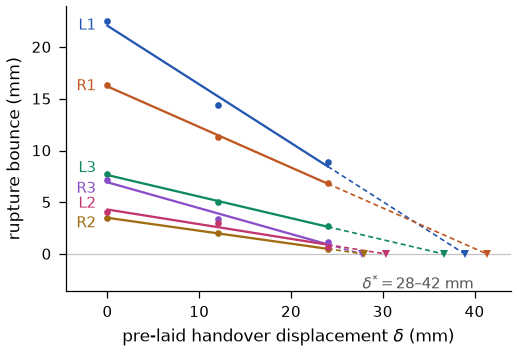
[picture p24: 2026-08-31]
paper/figures/fig_bounce_delta.png

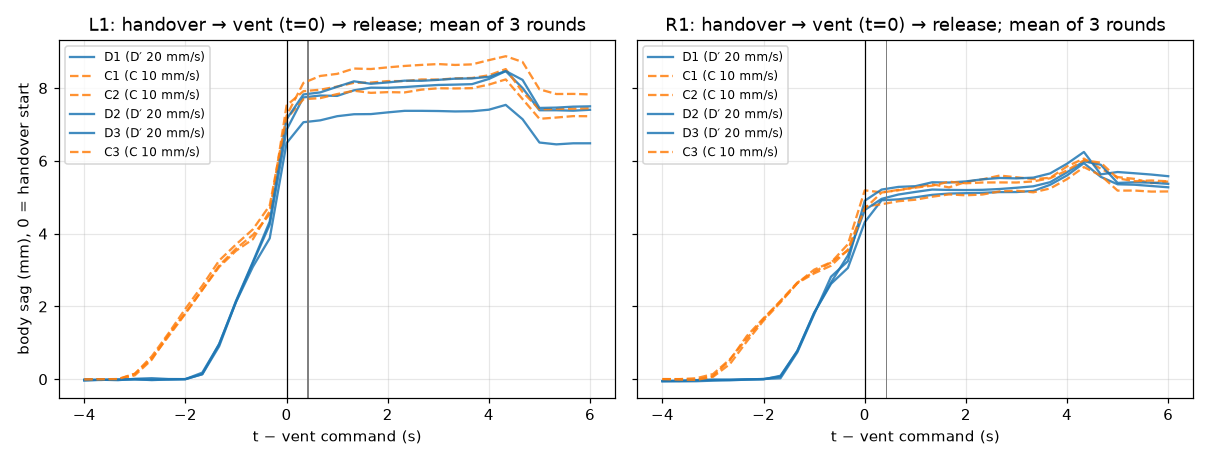
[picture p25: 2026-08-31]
paper/figures/dprime_profile.png

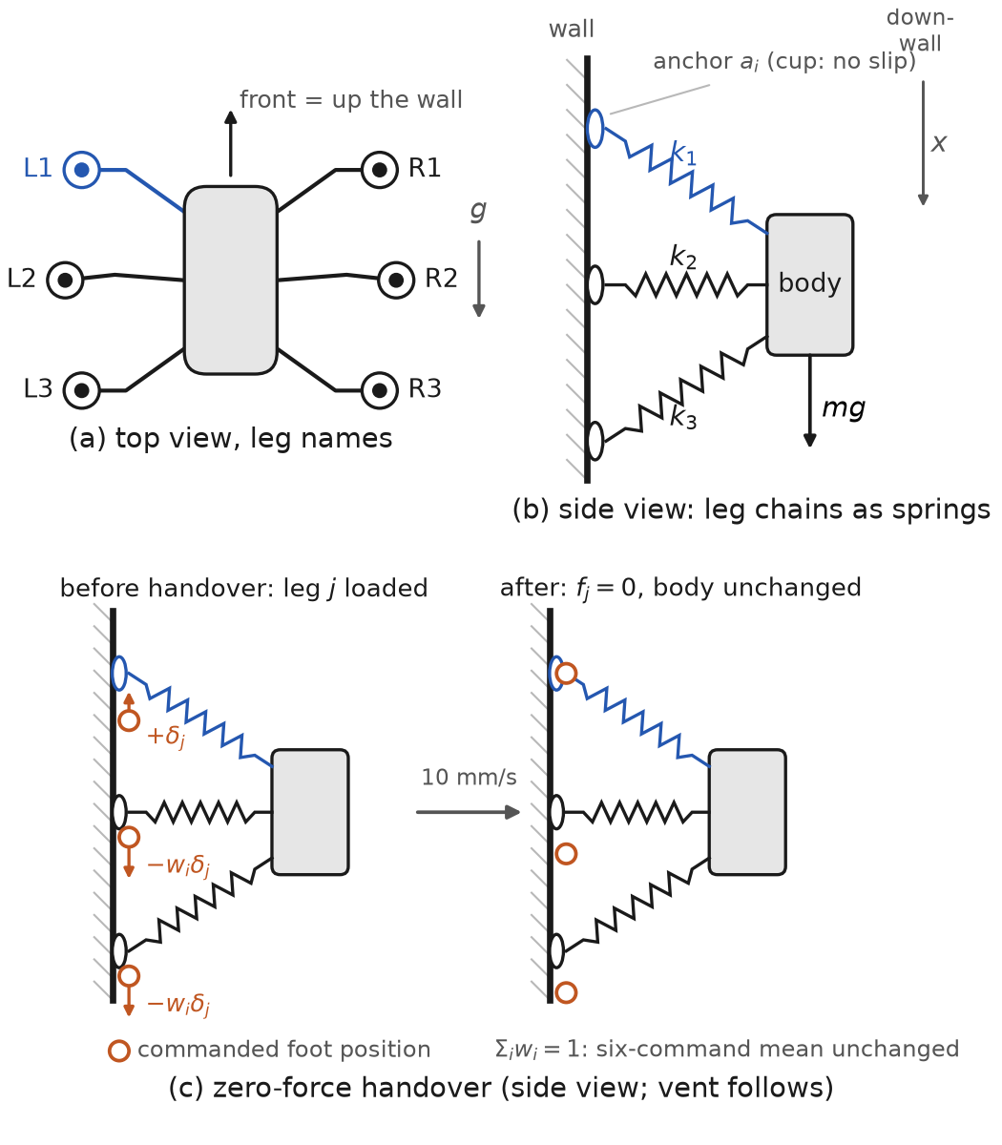
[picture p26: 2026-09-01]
paper/figures/fig_platform.png

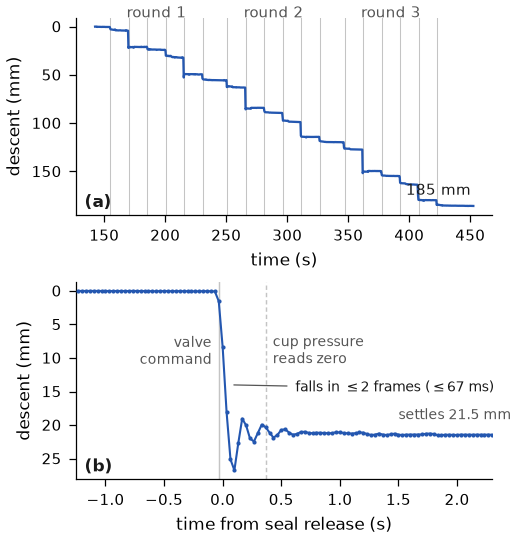
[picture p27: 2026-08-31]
paper/figures/fig_staircase_zoom.png

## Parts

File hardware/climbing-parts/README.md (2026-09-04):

# 自制爬墙部件（hardware/climbing-parts/）

全部由 [`tools/generate_climbing_parts.py`](../../tools/generate_climbing_parts.py) 参数化生成。协议与第三方派生说明见 [NOTICE.md](NOTICE.md)。

| 文件 | 用途 |
|---|---|
| `left-tibia-suction.stl` | **定版吸盘小腿**：与 MakeYourPet left-tibia 一体化（替代 left-tibia.stl + 旧吸盘足，腿短约 59mm）。末端腔体按实购"2.5 折吸盘+双六角螺母+直角宝塔"一体件（`images/xipan_marked.jpeg`）做全形状负模：Ø27 折痕座圈 + 45° 肩面 → Ø17 主孔 → Ø15 凹槽凸筋 → 六角袋锁转动 → 弯头腔。打印 3 件 |
| `right-tibia-suction.stl` | 定版右腿吸盘小腿：由左腿沿 XZ 平面镜像生成，与官方左右 tibia 的变换一致；打印 3 件，配同款 `suction-foot-door.stl` |
| `suction-foot-door.stl` | 定版吸盘腔门盖：含前半负模、4 个定位销和 2 个 M5 沉头过孔，左右腿共用；宝塔嘴从门顶开口伸出、可转动 |
| `component_plate.stl` | M3 网格安装板，固定真空泵/电磁阀/传感器 |
| `coxa-pedestal.stl`、`carriage-pedestal.stl` | P2 单腿台架用的支座与滑车一体件（`html/coxa-pedestal-mount.html`） |
| `p4-bay-v0/`、`p4-bay-v1/` | P4 电气+气动舱固定件（设计见 `docs/P4-BAY-DESIGN.md`，v0 目录内有装配图与 README） |
| `*-exp.stl` | 带触地环的试验版，未采用 |

## 打印建议

- PETG 优先。
- 左右 `tibia-suction` 均**立打**（吸盘腔朝下、tibia 朝上，5~6 壁、45% 填充、开 brim ≥8mm，tibia 细节可开支撑保险）。原因：方轴轴线距 tibia 平背面仅 4.5mm 而腔体半径 17mm，平躺必穿打印床，几何上只能立打。
- `suction-foot-door` 外平面朝下平躺、无支撑。

## 尺寸不符时重新生成

吸盘颈部直径之类与实购件不符时，改脚本顶部 `PARAMS` 后重新运行：

```bash
python3 -m venv .venv && .venv/bin/pip install trimesh manifold3d numpy scipy shapely
.venv/bin/python tools/generate_climbing_parts.py
```

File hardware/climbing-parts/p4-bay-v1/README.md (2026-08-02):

# P4 可拆器件舱 V1

本目录由 `tools/generate_p4_bay_v1.py` 生成。V1 保留 V0 的 190 × 130 mm
外廓和原车架 `(±44, ±40)` 四孔，但重新设计下层器件安装、100 mm 电气夹层
和线束出口。V0 目录没有被覆盖。

## 生成与验证

```bash
venv/bin/python tools/generate_p4_bay_v1.py
venv/bin/python tools/validate_p4_bay_v1.py
```

当前校验结果为 **22 passed, 0 failed**：

- 恰好 13 个 STL，全部水密、单连通体、正体积；
- 21 个已定位打印件实例无正体积碰撞；
- 41 条选定螺钉通路同时贯通模块和承载件；
- 7 块 PCB 外廓、同面间距以及 10 个端子/弯线服务区合格；
- 7 个传感器下向针脚通道、6 个阀下向塑料嘴通道均贯通。

`layout-report.json` 是装配坐标、板孔、接线服务区和验证输入的机器可读记录。

## 打印清单

| STL | 数量 | 说明 |
|---|---:|---|
| `p4-bay-fit-template-v1.stl` | 1 | 第一件打印，只验证车架动态净空 |
| `p4-bay-baseplate-v1.stl` | 1 | PETG，平底板，无 V0 开口凸筋 |
| `p4-bay-electrical-deck-v1.stl` | 1 | PETG，184 × 108 mm，开放式板边出线口 |
| `p4-bay-deck-post-100mm-v1.stl` | 6 | 试装件；正式优先用金属 M3 隔柱 |
| `p4-bay-spacer-m25-6mm-v1.stl` | 4 | Pi 5 |
| `p4-bay-spacer-m3-6mm-v1.stl` | 24 | 其余 6 块 PCB，每板 4 个 |
| `p4-bay-pump-adapter-v1.stl` | 2 | 左右共件，右件安装时旋转 180° |
| `p4-bay-pump-pad-tpu-v1.stl` | 2 | TPU 95A，泵支架减振 |
| `p4-bay-valve-rail-v1.stl` | 1 | 6 个 0520B 竖装位 |
| `p4-bay-sensor-bridge-v1.stl` | 1 | 7 个传感器，2+2+2+1 排布 |
| `p4-bay-manifold-clip-v1.stl` | 2 | 歧管轴线约 `Y=-49.5, Z=65`，需支撑 |
| `p4-bay-switch-bracket-v1.stl` | 1 | KCD1、保险/XT60 扎带位 |
| `p4-bay-cable-comb-v1.stl` | 4 | 左侧信号、右侧功率各两只 |

## 装配和连线方向

- 两台泵中心为 `(-46, 24)`、`(46, 24)`；泵支架与适配板之间放 TPU 垫。
- 阀轨中心为 `(0, -44.5)`。六只阀竖装，底部塑料嘴向下、侧嘴朝 `-Y`，
  阀轨中部不再用实体横梁封死气嘴。
- 传感器桥中心为 `(0, 12)`，桥板底面装配高度为 16 mm；针脚穿过桥板窗口，
  下方三条齐平横梁避开全部 7 个窗口。
- 歧管位于阀组后侧，减少六根阀管的交叉；泵管从两侧进入，不能压过阀线圈
  或传感器取压管。
- 电气甲板左侧走 GPIO、I²C/模拟传感器线，右侧走电池、泵和阀功率线；两类
  线束分别进入左右 cable comb，不共用束带。
- 顶面：分压汇接板在左、Pi 5 在中、5 V 降压板在右；底面：继电器在左，
  两块 XL6009 沿后缘，YYNMOS-8 在右前。板边保留端子起子和线弯空间。
- 泵和阀电流必须走继电器/MOSFET 与独立降压功率路径；Pi 只提供控制信号，
  不从 GPIO 引脚给泵、阀或继电器负载供电。

## 打印前仍须实测

自动校验只能证明当前尺寸代理之间不相撞，不能代替实物公差验证。正式打印
底板前仍须完成：

1. 用 fit template 在六腿全行程和实际线束状态下做慢速动态扫掠；
2. 复核 555 泵体相对 48 × 28 mm 支架孔中心的前后偏置；
3. 复核 0520B 两个塑料嘴的实际伸出量（V1 代理按 12 mm）；
4. 先各打印一个泵适配板、阀轨和传感器桥，确认孔径与压配间隙；
5. 储气罐到货前不生成抱箍，避免依据未知耳距制造。

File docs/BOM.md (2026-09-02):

# 采购清单（BOM）

价格为淘宝/拼多多常见价区间（2026 年中），仅供预算参考。括号内为淘宝搜索关键词。

## 分批采购（重要）

风险前置：**P2 单腿上墙决策门通过之前，只买第一批。**

**第一批 · 单腿验证套件（P0~P2，约 ¥600~950）**

- 表 1 中：舵机 ×4（3 用 1 备）、Servo2040 ×1、5V/5A 降压 ×1、2S 电池 ×1、螺丝/定位销/线材（按一条腿的量）
- 表 2 中：真空泵 ×1、电磁阀 ×2、吸盘 ×3、XGZP6847A ×1、ADS1115 ×1、MOSFET 板 ×1、XL6009 ×1、硅胶管/接头/单向阀
- 另需：试验台材料（木板/铝型材、竖直导轨滑车或抽屉滑轨、1.5kg 配重）

**第二批 · 整机（P2 决策门通过后，约 ¥1100~1900）**

- 表 1 剩余：舵机 ×16（凑 18+2 备）、舵机电源 MOS 开关模块 ×1、足底开关、其余螺丝耗材
- 表 2 剩余：泵 ×1、阀 ×6、吸盘 ×5、压力传感器 ×6（凑 7 = 每足 1 + 罐 1）、ADS1115 ×1、真空歧管 ×1、XL6009 ×1（凑 2）、安全绳；硅胶管盘余量，不足补 5m
- 第二批即整机全量采购，**P4 仅追加管路滤芯一项**（2026-08-17 灰尘风险评估补入，见表 2；40mm 吸盘/双泵并联仍是数据触发的升级，非计划项）
- 表 3 按需

## 表 1 · 步行平台（MakeYourPet，P0 买 4 舵机，其余 P3 前买齐）

| 器件 | 规格 | 数量 | 单价参考 | 备注 |
|---|---|---|---|---|
| 数字舵机 | 35kg·cm 无核/铁芯 270°→限180°（`DS3235 35kg 舵机`） | 18 + 2 备 | ¥45~85 | 原版用 ZOSKAY 35kg；买 180° 控制角版本 |
| 舵机控制板 | Pimoroni Servo2040（`Servo2040` 或海淘） | 1 | ¥150~220 | 跑社区 chica 固件，Pi 经 USB 驱动；省钱替代：2× PCA9685（¥15/块，需自己改 driver.py 并管舵机电源轨） |
| 大脑 | 树莓派 Pi 5 4GB + 官方主动散热器 | 1 | 已有 | 跑 `software/` 自研步态软件（Raspberry Pi OS Lite 64-bit + SSH） |
| Pi 供电 | 5V/5A DC-DC 降压模块（`5V 5A 降压模块`） | 1 | ¥15~25 | **必须独立供电，不与舵机共轨**——舵机堵转压降会让 Pi 重启，爬墙时重启=掉落。装好后 `vcgencmd get_throttled` 确认无欠压 |
| 电池 | 2S 7.4V 5000~6200mAh 锂电（`2S 航模锂电池 XT60`） | 1 | ¥80~150 | 舵机 7.4V 直供；配 B3 充电器 ¥25 |
| 足底开关 | 微动限位开关（`KW10 微动开关`） | 6 + 备 | ¥0.5~1 | 触地检测，爬墙步态刚需 |
| 螺丝 | M1.6×6 杯头 ×120、M2.5×6 ×10、M3 若干（`M1.6 内六角 碳钢`） | 各1包 | ¥10~20/包 | 按 STL 版本核对官方 README 的 fan parts list |
| 定位销 | Φ3 圆柱销（`3mm 定位销`） | 6 | ¥5/包 | 腿关节转轴 |
| 橡胶足尖 | 9mm 内径橡胶帽（`橡胶保护帽 9mm`） | 6 | ¥5~10 | 地面行走用；爬墙时换吸盘足 |
| 舵机电源开关 | 持续 ≥15A、3.3V 可触发：首选 30A 继电器模块（`30A 继电器模块 5V 光耦` 低电平触发）；或 15A MOS 模块（`MOS管触发开关驱动模块 15A 400W`）×2 并联 | 1 | ¥5~20 | **Pi GPIO17（Pin11）控舵机 7.4V 总电**（08-15 改，原定 Servo2040 A0/GPIO26）；已购 H/L 可选触发版，跳线必须插 **H**，线圈 DC+ 取 5V/5A 降压输出、DC− 共地。**必须切正极高边**（地经 USB 与 Pi 共通，低边开关会被旁路）。载荷依据 P2 实测：单腿压紧峰值 0.73A，整机持续 2~4A/瞬态 ~12A。到手三查：IN 悬空=断、3.3V=通、释放=断 |
| 电源开关/线材 | XT60 插头、16AWG 硅胶线、热缩管、杜邦线 | 若干 | ¥30 | |
| 打印耗材 | PLA 或 PETG 1.75mm | 2kg | ¥50~110 | 腿部件 4 壁 40% 填充 |

**小计约 ¥1300~2200**（舵机占大头）。

## 表 2 · 真空吸附系统（P1/P2 单腿验证起用）

| 器件 | 规格 | 数量 | 单价参考 | 备注 |
|---|---|---|---|---|
| 微型真空泵 | 555 双头隔膜泵 12V，极限 -75~-85kPa（`555 双头真空泵 12V`） | 2 | ¥25~60 | 一主一备/并联提速 |
| 电磁阀 | 二位三通 12V **常闭**（`0520B 三通电磁阀 12V 常闭`） | 6 + 2 备 | ¥10~20 | 常闭=断电保持真空，选型关键 |
| 真空吸盘 | 30mm 2.5 折波纹吸盘 + **M5 通孔金具 + 弯头宝塔接头**（`机械手真空吸盘 30mm 波纹 M5`） | 8 | ¥5~15 | 波纹结构自带角度顺应性；P5 负重升级 40mm |
| 压力传感器 | XGZP6847A 0~-100kPa 模拟输出（`XGZP6847 真空压力传感器`） | 3~6 | ¥15~25 | 至少泵后 1 个 + 轮询各足；理想每足 1 个 |
| 硅胶管 | 4×6mm 食品级硅胶管 | 5m | ¥15 | 配 4mm 三通/直通/单向阀各一包 |
| 单向阀 | 4mm 气动单向阀（`气动单向阀 4mm`） | 2 | ¥3~8 | 泵与储气罐之间 |
| 管路滤芯 | 4mm 管路真空滤芯，烧结/毡芯（`真空过滤器 4mm` 或 SMC ZFC 同款） | 6 + 2 备 | ¥2~10 | **P4 追加（2026-08-17）**：每足 1 只，装在吸盘与足压三通之间（吸盘侧）。防灰尘进管路——堵传感器取压口会封住真空假装 ATTACHED、垫住单向阀阀座会静默失去漏气隔离、进泵头会让极限真空度变差泵连转，三者都不易察觉。装后复测抽气时间（滤芯有流阻） |
| 真空歧管 | 1 进 6 出分配器（`气动歧管 4mm 一进六出`） | 1 | ¥10~20 | 罐 → 6 路阀的分配；整体件比三通串链少 8 个插接点（接点=泄漏点） |
| 储气罐 | 空 PET 瓶/打印罐 + 瓶盖接头 | 1 | ~¥0 | 平滑压力波动、加快响应 |
| 阀驱动 | 8 路 MOSFET 板（`8路 MOS管 驱动模块`） | 1 | ¥15~30 | 驱动 6 阀 + 2 泵，控制脚直接接 Pi 5 GPIO |
| 升压模块 | 2S 7.4V → 12V DC-DC 3A（`XL6009 升压模块`） | 2 | ¥8~15 | 泵/阀是 12V 件 |
| ADC 模块 | ADS1115 16 位 I2C 4 通道（`ADS1115 模块`） | 2 | ¥10~15 | Pi 没有模拟输入，读 XGZP6847A 用；两块共 8 通道，I2C 地址 0x48/0x49 |
| 安全绳 | 3mm 辅绳 10m + 小钢锁 2 + 膨胀挂点 | 1套 | ¥40~70 | P4 起全程使用 |

**小计约 ¥350~600**。

## 表 3 · P5 扩展（按需购买）

| 器件 | 用途 | 参考价 |
|---|---|---|
| 40mm 波纹吸盘 ×6 | 负重升级（法向力 ×1.8） | ¥8~18/个 |
| 树莓派摄像头模块 3（CSI 排线接 Pi 5） | FPV 视频流 | ¥120~180 |
| MPU6050 | 滑坠检测（姿态突变 → 全阀锁定） | ¥8 |
| 蜂鸣器 + 电压检测模块 | 低压报警（掉电=掉落） | ¥10 |
| ReSpeaker Lite 单板版（XMOS XU316 双麦，USB）+ 4Ω 3W PH2.0 喇叭 | 语音交互（**2026-09 已购**，见 `docs/VOICE-GUIDE.md`；USB 免驱、不占 GPIO，板载 AEC/降噪，喇叭直插板上 SPK 口。曾买 2-Mics Pi HAT，因 GPIO18~21 与气路冲突退换） | ¥100~150 + ¥5 |

## 工具（若没有）

3D 打印机（打印体积 ≥200×200mm）、电烙铁 + 焊锡、热熔胶枪、万用表、十字/内六角螺丝刀组、剥线钳、502 + 环氧胶、桌面台钳。

---

### 采购要点

1. **舵机别买杂牌最低价**——爬墙时舵机堵转是常态，齿轮打齿=整机掉落。35kg 档买 ZOSKAY/DSservo 等有口碑的店。
2. **电磁阀必须常闭型**（断电时吸盘保持真空），买之前问清楚。
3. 吸盘选**带直角宝塔弯头的一体件**（已购：2.5 折波纹吸盘，第一折痕 Ø27、凹槽 Ø15×1.7、双六角螺母边长 7/5、弯头高 13、宝塔嘴伸出 24、软管外径 6，见 `images/xipan_marked.jpeg` 三视图）；`left-tibia-suction.stl` 的腔体按此全形状负模设计，换不同规格需改 `tools/generate_climbing_parts.py` 的 `PARAMS` 重新生成。
4. Servo2040 海淘周期长，可先用舵机测试仪调装配，控制板后到。

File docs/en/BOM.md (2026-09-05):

> English translation of [`docs/BOM.md`](../BOM.md). The Chinese original is the maintained source; if they differ, the Chinese version wins.

# Bill of materials (BOM)

Prices are the usual Taobao / Pinduoduo range (mid-2026) and are for budgeting only. The terms in parentheses are Taobao search keywords.

## Buying in batches (important)

Risk first: **do not buy anything beyond the first batch until the P2 single-leg wall decision gate has passed.**

**Batch 1 · single-leg validation kit (P0–P2, about ¥600–950)**

- From table 1: servos ×4 (3 in use, 1 spare), Servo2040 ×1, 5V/5A buck ×1, 2S battery ×1, screws / dowel pins / wire (enough for one leg)
- From table 2: vacuum pump ×1, solenoid valves ×2, suction cups ×3, XGZP6847A ×1, ADS1115 ×1, MOSFET board ×1, XL6009 ×1, silicone tubing / fittings / check valves
- Also needed: test-rig material (plywood or aluminum extrusion, a vertical rail carriage or drawer slide, 1.5 kg of ballast)

**Batch 2 · whole robot (after the P2 decision gate, about ¥1100–1900)**

- Rest of table 1: servos ×16 (making 18 + 2 spare), servo-power MOS switch module ×1, foot contact switches, remaining screws and consumables
- Rest of table 2: pump ×1, valves ×6, suction cups ×5, pressure sensors ×6 (making 7 = 1 per foot + 1 on the tank), ADS1115 ×1, vacuum manifold ×1, XL6009 ×1 (making 2), safety line; use up what is left on the silicone tubing reel and top up with 5 m if short
- Batch 2 is the full whole-robot purchase; **P4 adds exactly one item, the line filters** (added 2026-08-17 after the dust risk assessment, see table 2; 40 mm cups and two pumps in parallel are still data-triggered upgrades, not planned items)
- Table 3 as needed

## Table 1 · Walking platform (MakeYourPet; buy 4 servos at P0, the rest before P3)

| Item | Spec | Qty | Unit price ref. | Notes |
|---|---|---|---|---|
| Digital servo | 35 kg·cm coreless/iron-core, 270° limited to 180° (`DS3235 35kg 舵机`, DS3235 35 kg servo) | 18 + 2 spare | ¥45–85 | The original build uses ZOSKAY 35 kg; buy the 180° control-angle version |
| Servo control board | Pimoroni Servo2040 (`Servo2040` or import it) | 1 | ¥150–220 | Runs the community chica firmware, driven from the Pi over USB; cheap alternative: 2× PCA9685 (¥15 each, you have to modify driver.py yourself and manage the servo power rail) |
| Brain | Raspberry Pi 5 4GB + official active cooler | 1 | already owned | Runs the in-house gait software in `software/` (Raspberry Pi OS Lite 64-bit + SSH) |
| Pi supply | 5V/5A DC-DC buck module (`5V 5A 降压模块`, 5 V 5 A buck module) | 1 | ¥15–25 | **Must have its own supply, never share the rail with the servos** — the voltage drop when a servo stalls will reboot the Pi, and a reboot while climbing = a fall. Once installed, confirm with `vcgencmd get_throttled` that there is no undervoltage |
| Battery | 2S 7.4V 5000–6200mAh LiPo (`2S 航模锂电池 XT60`, 2S RC LiPo battery XT60) | 1 | ¥80–150 | Feeds the servos directly at 7.4 V; add a B3 charger, ¥25 |
| Foot contact switch | Micro limit switch (`KW10 微动开关`, KW10 micro switch) | 6 + spares | ¥0.5–1 | Ground contact detection, a hard requirement for the climbing gait |
| Screws | M1.6×6 cap head ×120, M2.5×6 ×10, assorted M3 (`M1.6 内六角 碳钢`, M1.6 hex socket, carbon steel) | 1 bag each | ¥10–20/bag | Check against the fan parts list in the official README for your STL version |
| Dowel pins | Φ3 cylindrical pin (`3mm 定位销`, 3 mm dowel pin) | 6 | ¥5/bag | Leg joint pivots |
| Rubber foot tips | 9mm ID rubber cap (`橡胶保护帽 9mm`, rubber protective cap 9 mm) | 6 | ¥5–10 | For floor walking; swapped for suction-cup feet when climbing |
| Servo power switch | Continuous ≥15A, triggerable at 3.3V: first choice a 30A relay module (`30A 继电器模块 5V 光耦`, 30 A relay module 5 V optocoupler, active-low trigger); or 15A MOS modules (`MOS管触发开关驱动模块 15A 400W`, MOSFET trigger switch driver module 15 A 400 W) ×2 in parallel | 1 | ¥5–20 | **Pi GPIO17 (Pin11) switches the servos' 7.4V main power** (changed 08-15; originally Servo2040 A0/GPIO26); the module bought has selectable H/L triggering, the jumper must go on **H**, coil DC+ from the 5V/5A buck output, DC− on common ground. **Must switch the positive high side** (ground is shared with the Pi through USB, so a low-side switch gets bypassed). Load basis, measured at P2: single-leg press peak 0.73A, whole robot 2–4A continuous / ~12A transient. Three checks on arrival: IN floating = off, 3.3V = on, released = off |
| Power switch / wire | XT60 connector, 16AWG silicone wire, heat-shrink, Dupont jumpers | assorted | ¥30 | |
| Print filament | PLA or PETG 1.75mm | 2kg | ¥50–110 | Leg parts at 4 walls, 40% infill |

**Subtotal about ¥1300–2200** (the servos dominate).

## Table 2 · Vacuum adhesion system (in use from the P1/P2 single-leg validation)

| Item | Spec | Qty | Unit price ref. | Notes |
|---|---|---|---|---|
| Miniature vacuum pump | 555 twin-head diaphragm pump 12V, ultimate -75 to -85kPa (`555 双头真空泵 12V`, 555 twin-head vacuum pump 12 V) | 2 | ¥25–60 | One main, one spare / in parallel for faster pumping |
| Solenoid valve | 3/2-way 12V **normally closed** (`0520B 三通电磁阀 12V 常闭`, 0520B 3-way solenoid valve 12 V normally closed) | 6 + 2 spare | ¥10–20 | Normally closed = holds vacuum when unpowered, the critical selection point |
| Vacuum suction cup | 30mm 2.5-fold bellows cup + **M5 through-hole fitting + barbed elbow** (`机械手真空吸盘 30mm 波纹 M5`, robot vacuum suction cup 30 mm bellows M5) | 8 | ¥5–15 | The bellows structure gives angular compliance for free; upgrade to 40 mm for the payload stage in P5 |
| Pressure sensor | XGZP6847A 0 to -100kPa analog output (`XGZP6847 真空压力传感器`, XGZP6847 vacuum pressure sensor) | 3–6 | ¥15–25 | At least 1 downstream of the pump + poll the feet; ideally 1 per foot |
| Silicone tubing | 4×6mm food-grade silicone tubing | 5m | ¥15 | Plus one bag each of 4 mm tees / unions / check valves |
| Check valve | 4mm pneumatic check valve (`气动单向阀 4mm`, pneumatic check valve 4 mm) | 2 | ¥3–8 | Between the pump and the vacuum tank |
| Line filter | 4mm inline vacuum filter, sintered or felt element (`真空过滤器 4mm`, vacuum filter 4 mm, or the SMC ZFC equivalent) | 6 + 2 spare | ¥2–10 | **Added at P4 (2026-08-17)**: one per foot, fitted between the cup and the foot-pressure tee (cup side). Keeps dust out of the lines — plugging the sensor's pressure tap seals the vacuum in and fakes ATTACHED, a grain under a check valve seat silently kills the leak isolation, and dust in the pump head degrades the ultimate vacuum so the pump runs continuously; none of the three is easy to notice. Re-measure the pump-down time after fitting them (a filter element adds flow resistance) |
| Vacuum manifold | 1-in-6-out distributor (`气动歧管 4mm 一进六出`, pneumatic manifold 4 mm 1-in-6-out) | 1 | ¥10–20 | Distributes tank → 6 valve lines; one part instead of a chain of tees saves 8 push-in joints (a joint = a leak point) |
| Vacuum tank | Empty PET bottle / printed tank + bottle-cap fitting | 1 | ~¥0 | Smooths pressure ripple, speeds up the response |
| Valve driver | 8-channel MOSFET board (`8路 MOS管 驱动模块`, 8-channel MOSFET driver module) | 1 | ¥15–30 | Drives 6 valves + 2 pumps, control pins wired straight to the Pi 5 GPIO |
| Boost module | 2S 7.4V → 12V DC-DC 3A (`XL6009 升压模块`, XL6009 boost module) | 2 | ¥8–15 | The pumps and valves are 12 V parts |
| ADC module | ADS1115 16-bit I2C 4-channel (`ADS1115 模块`, ADS1115 module) | 2 | ¥10–15 | The Pi has no analog input; needed to read the XGZP6847A. Two boards give 8 channels, I2C addresses 0x48/0x49 |
| Safety line | 3mm accessory cord 10m + 2 small carabiners + an expansion anchor | 1 set | ¥40–70 | Used at all times from P4 on |

**Subtotal about ¥350–600**.

## Table 3 · P5 extensions (buy as needed)

| Item | Purpose | Price ref. |
|---|---|---|
| 40mm bellows cups ×6 | Payload upgrade (normal force ×1.8) | ¥8–18 each |
| Raspberry Pi Camera Module 3 (CSI ribbon to the Pi 5) | FPV video stream | ¥120–180 |
| MPU6050 | Fall detection (sudden attitude change → lock all valves) | ¥8 |
| Buzzer + voltage monitor module | Low-voltage alarm (power loss = fall) | ¥10 |
| ReSpeaker Lite single board (XMOS XU316 dual mic, USB) + 4Ω 3W PH2.0 speaker | Voice interaction (**bought 2026-09**, see `docs/en/VOICE-GUIDE.md`; USB, driverless, uses no GPIO, on-board AEC/noise reduction, the speaker plugs straight into the board's SPK socket. A 2-Mics Pi HAT was bought first and returned because GPIO18–21 clashed with the pneumatics) | ¥100–150 + ¥5 |

## Tools (if you do not have them)

3D printer (build volume ≥200×200mm), soldering iron + solder, hot glue gun, multimeter, Phillips/hex screwdriver set, wire strippers, cyanoacrylate + epoxy, bench vise.

---

### Buying notes

1. **Do not buy the cheapest no-name servos** — stalling is normal when climbing, and stripped gears = the whole robot falls. In the 35 kg class buy from a shop with a reputation, e.g. ZOSKAY or DSservo.
2. **The solenoid valves must be the normally closed type** (the cups keep their vacuum when the power is off). Ask before you buy.
3. Pick cups that are a **one-piece part with a right-angle barbed elbow** (bought: 2.5-fold bellows cup, first crease Ø27, groove Ø15×1.7, twin hex-nut flats 7/5, elbow height 13, barb spout protruding 24, hose OD 6; see the three-view in `images/xipan_marked.jpeg`); the cavity in `left-tibia-suction.stl` is designed as a negative of that exact shape, so a different cup means editing `PARAMS` in `tools/generate_climbing_parts.py` and regenerating.
4. The Servo2040 takes a long time to import, so you can do the assembly tuning with a servo tester first and let the control board arrive later.

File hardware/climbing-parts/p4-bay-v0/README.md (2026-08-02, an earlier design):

# P4 电气+气动舱 V0

本目录由 `tools/generate_p4_bay_v0.py` 生成。V0 是**实物试装版**,不是未经
验证即可爬墙的终版。全部 13 个 STL 已通过水密、有限顶点和正体积检查；
孔位、尺寸与打印数量见 `layout-report.json`。

`p4-bay-v0-lower-layout.png` 和 `p4-bay-v0-assembly.png` 是包络检查预览；
其中彩色方块/圆柱只是按实测外形或保守高度建立的器件代理,不是打印件。

按下表数量、不含 1mm 模板时,几何实体体积约 237.2cm³；全实心 PETG/TPU
质量上限约 301g。实际切片会因填充率降低,但必须以打印后称重为准。V0 用于
试装；通过后还要做 V1 镂空/薄壁减重,目标打印固定件不超过 180g。

## 必须先打印的件

先打 `p4-bay-fit-template-v0.stl`。它是 190×130×1mm 外廓模板,中央开口和
frame 接口与正式底板一致。只用原有 `(±44,±40)` 四孔装到 frame,装好六个
coxa 舵机和线夹后做全行程检查。任何一处擦线或碰舵机,都应先改底板外廓,
不要继续打印正式底板。

`(±44,0)` 两孔只是可选加强位。确认其下方为实心且确有必要后,才给 frame
钻 Ø2.8mm M3 自攻底孔。

## STL 与数量

| 文件 | 数量 | 材料 |
|---|---:|---|
| `p4-bay-fit-template-v0.stl` | 1 | PLA/PETG |
| `p4-bay-baseplate-v0.stl` | 1 | PETG |
| `p4-bay-electrical-deck-v0.stl` | 1 | PETG |
| `p4-bay-deck-post-90mm-v0.stl` | 6 | PETG,仅试装 |
| `p4-bay-spacer-m25-6mm-v0.stl` | 4 | PLA/PETG |
| `p4-bay-spacer-m3-6mm-v0.stl` | 按需约 20 | PLA/PETG |
| `p4-bay-pump-adapter-v0.stl` | 1 | PETG |
| `p4-bay-pump-pad-tpu-v0.stl` | 1 | TPU 95A |
| `p4-bay-valve-rail-v0.stl` | 1 | PETG |
| `p4-bay-sensor-block-v0.stl` | 1 | PLA/PETG,4+3 双排 |
| `p4-bay-manifold-clip-v0.stl` | 2 | PETG |
| `p4-bay-switch-bracket-v0.stl` | 1 | PETG |
| `p4-bay-cable-comb-v0.stl` | 4 | PLA/PETG |

## 建议打印与紧固

- 0.20mm 层高、4 道墙、5 层顶/底、30%~40% gyroid；底板和甲板平躺。
- 泵用 4×M4、大垫圈和 3mm TPU 垫；螺丝只压到不窜动,不要压死 TPU。
- Pi 用 M2.5；其他 PCB 用 M3；所有 PCB 与甲板之间装 6mm 隔柱。
- 阀轨每只阀用一条 2.5mm 扎带；传感器试插合适后用少量中性硅胶点固。
- 90mm 打印柱用于确认高度和孔位。正式爬墙优先改用 M3×90 金属/尼龙
  六角柱或两段组合柱,并使用防松螺母。
- 储气罐尺寸尚未实测,本目录没有罐抱箍；到货后再生成 V1。

重新生成:

```bash
venv/bin/python tools/generate_p4_bay_v0.py
```

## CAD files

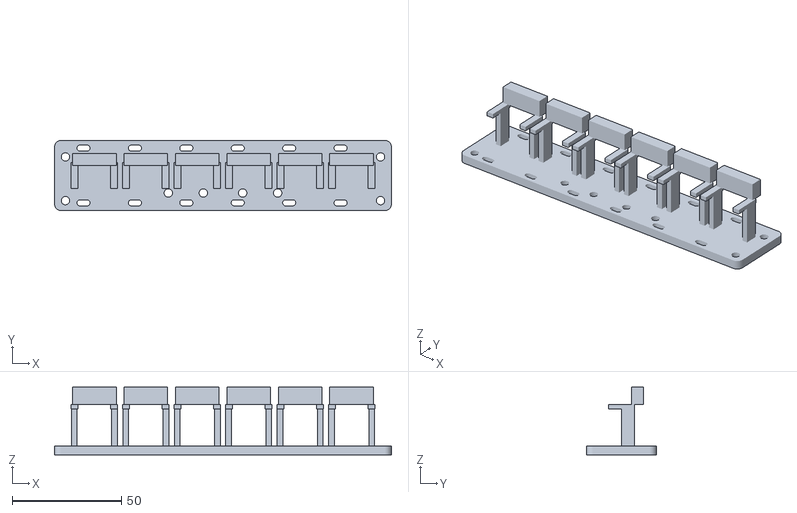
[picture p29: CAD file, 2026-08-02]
hardware/climbing-parts/p4-bay-v1/p4-bay-valve-rail-v1.stl
154.0 x 32.0 x 30.9

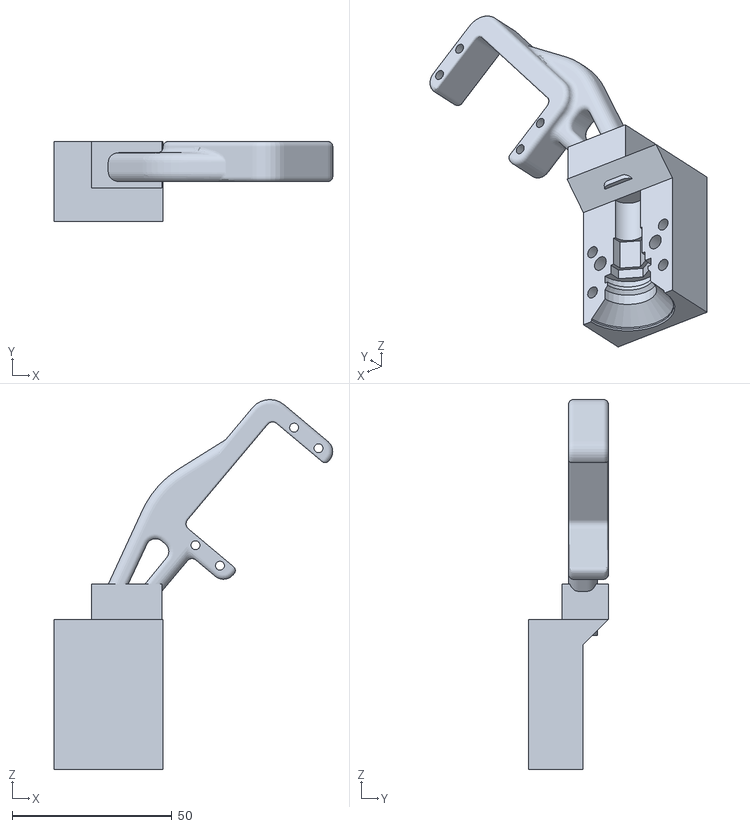
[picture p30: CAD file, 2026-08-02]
hardware/climbing-parts/right-tibia-suction.stl
87.2 x 25.0 x 115.8

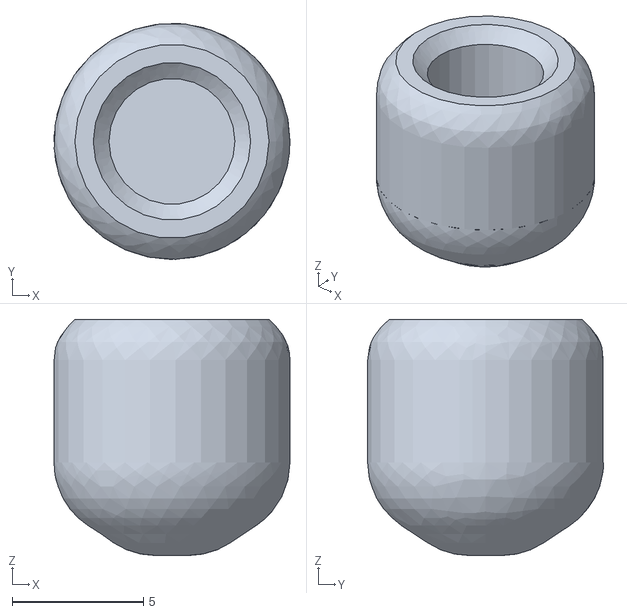
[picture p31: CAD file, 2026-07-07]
hardware/makeyourpet-hexapod/Chipo/tip.stl
9.00 x 8.99 x 9.00

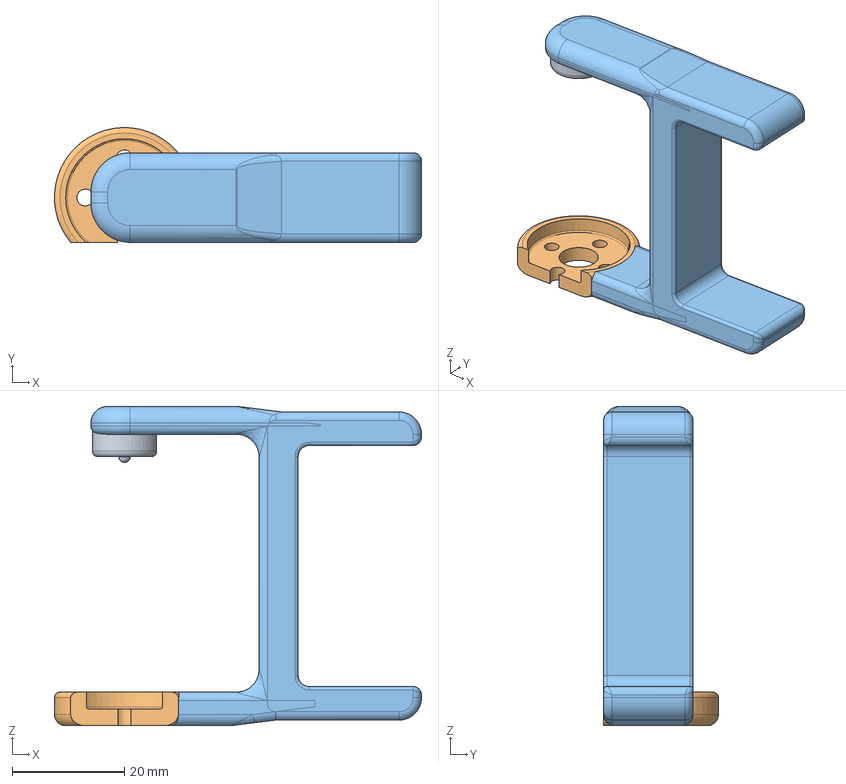
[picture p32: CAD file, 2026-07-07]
hardware/makeyourpet-hexapod/Metal Horn/STEP/coxa.step
65.5 x 20.5 x 57.0 mm

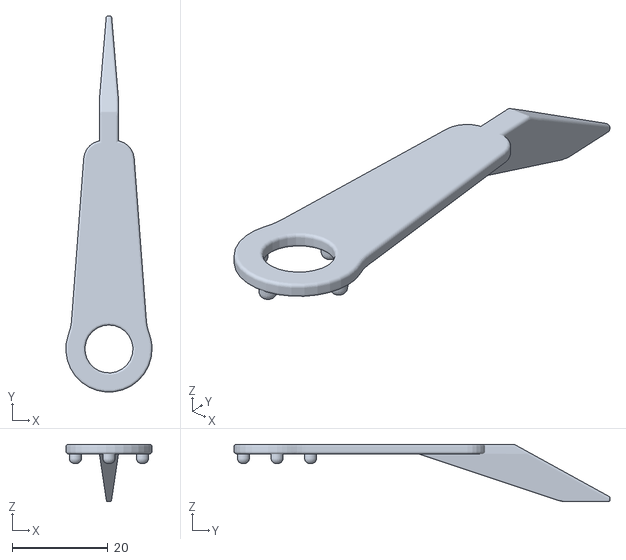
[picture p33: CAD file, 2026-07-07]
hardware/makeyourpet-hexapod/Metal Horn/STL/calib-arm.stl
18.0 x 78.5 x 12.0

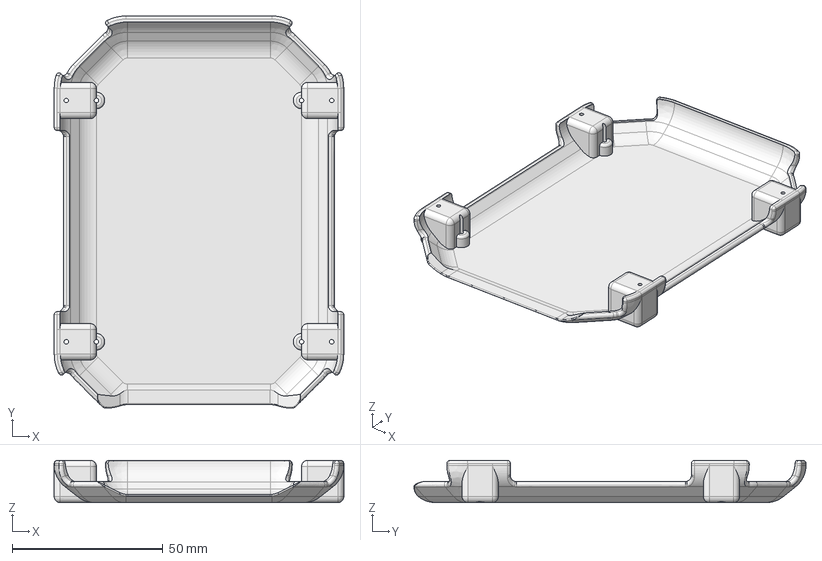
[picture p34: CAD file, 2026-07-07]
hardware/makeyourpet-hexapod/STEP/bottom-cover-flat.step
96.0 x 130.0 x 14.0 mm

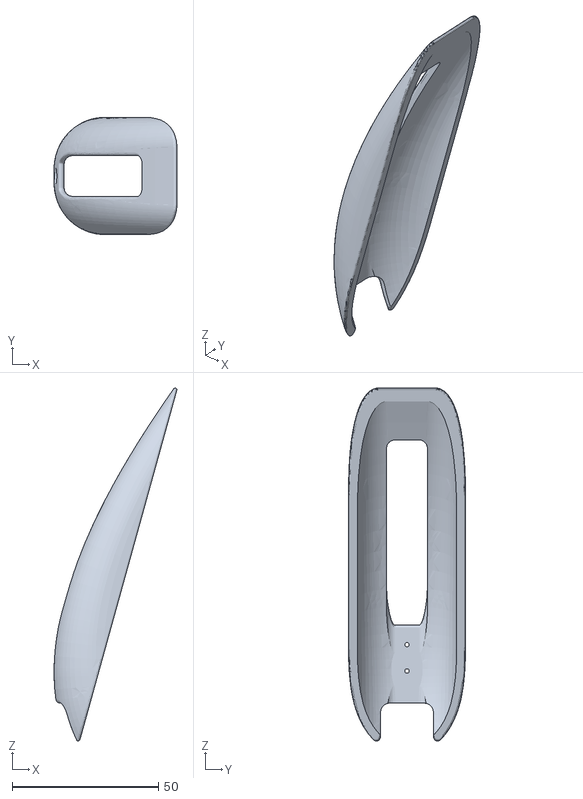
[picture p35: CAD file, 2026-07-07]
hardware/makeyourpet-hexapod/STL/shield.stl
42.0 x 40.0 x 120.6

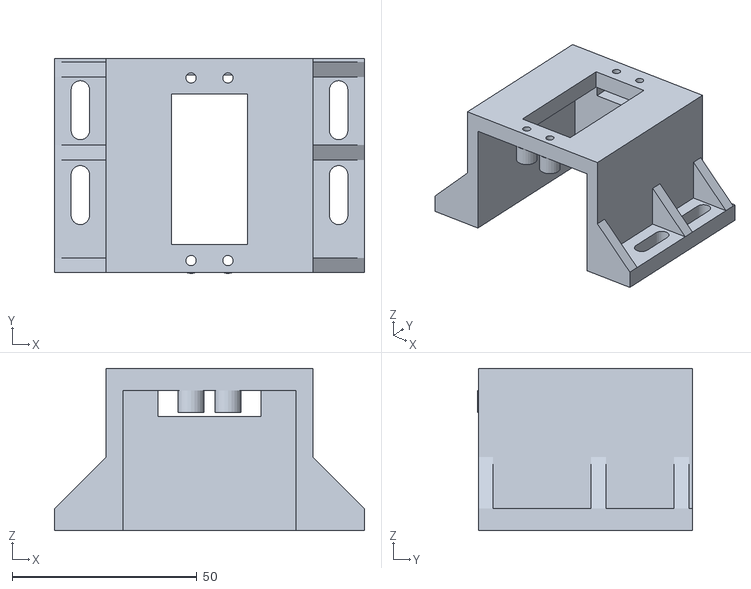
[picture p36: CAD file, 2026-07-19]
hardware/climbing-parts/coxa-pedestal.stl
84.0 x 58.2 x 44.0

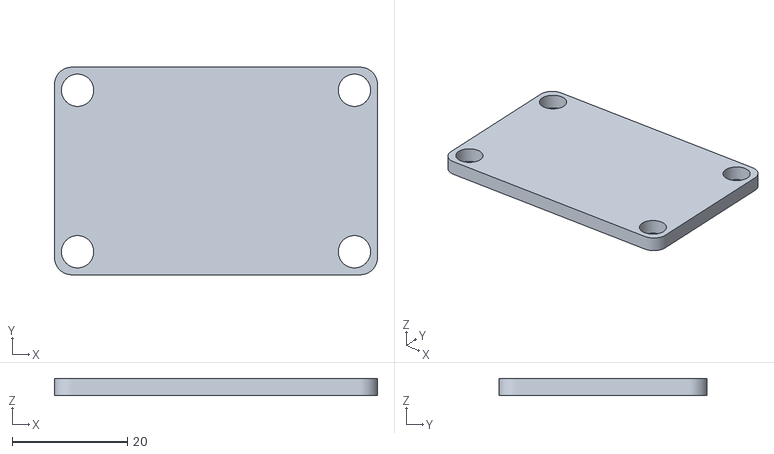
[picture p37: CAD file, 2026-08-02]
hardware/climbing-parts/p4-bay-v1/p4-bay-pump-pad-tpu-v1.stl
56.0 x 36.0 x 3.00

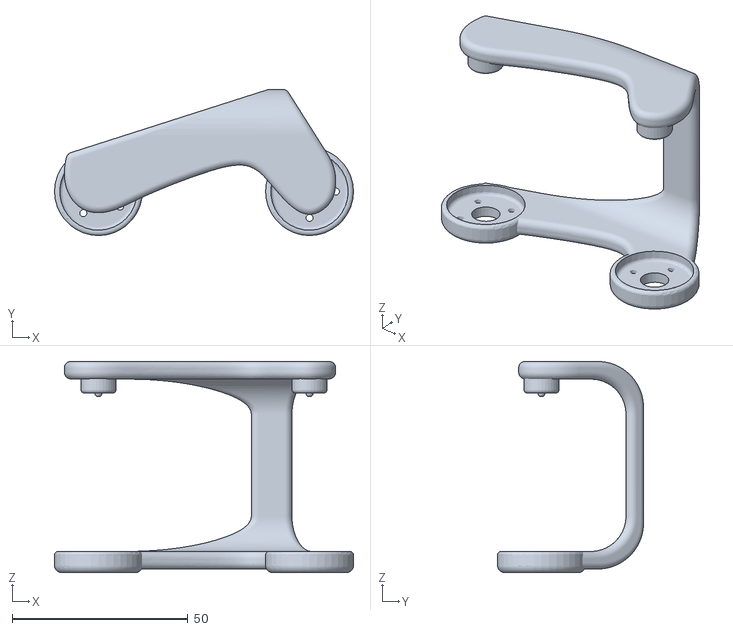
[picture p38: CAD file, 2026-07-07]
hardware/makeyourpet-hexapod/Chipo/femur-996.stl
85.0 x 41.5 x 60.0

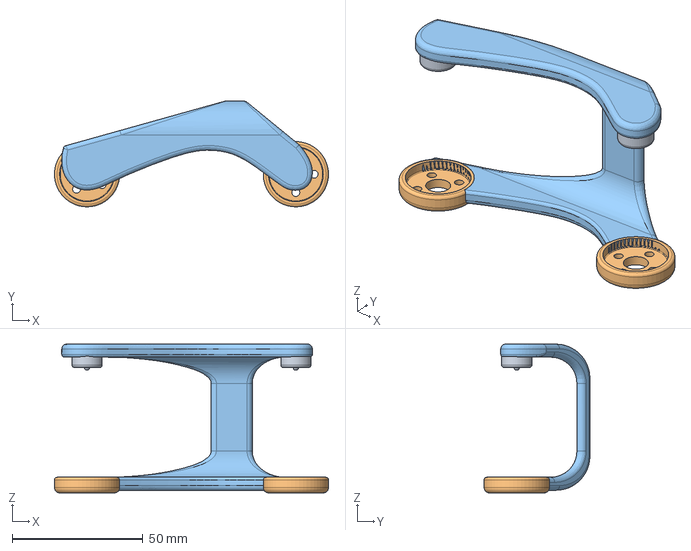
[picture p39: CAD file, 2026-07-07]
hardware/makeyourpet-hexapod/Metal Horn/STEP/femur.step
105.0 x 40.5 x 57.0 mm

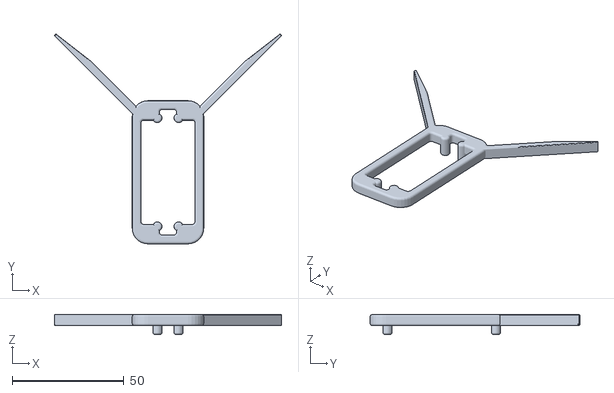
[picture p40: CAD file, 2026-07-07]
hardware/makeyourpet-hexapod/Metal Horn/STL/calib-ruler.stl
101.5 x 93.8 x 9.00

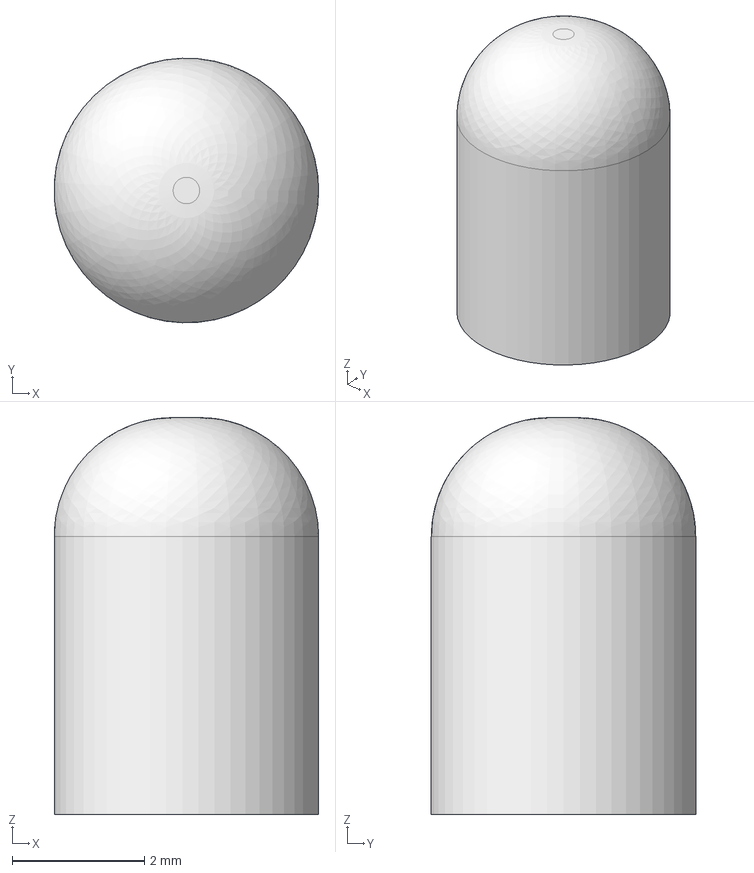
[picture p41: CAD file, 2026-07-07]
hardware/makeyourpet-hexapod/STEP/limiter.step
4.00 x 4.00 x 6.00 mm

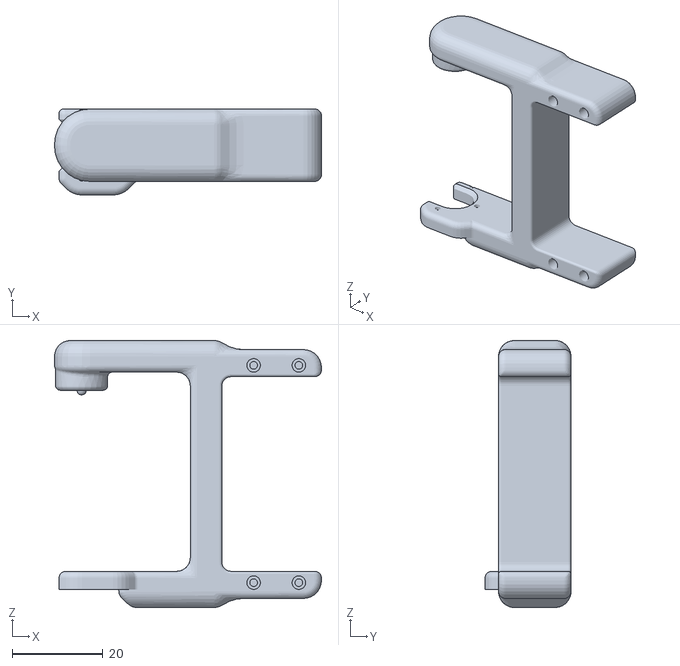
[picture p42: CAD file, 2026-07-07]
hardware/makeyourpet-hexapod/STL/right-coxa2.stl
59.0 x 19.0 x 59.0

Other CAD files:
hardware/climbing-parts/carriage-pedestal.stl
hardware/climbing-parts/p4-bay-v1/p4-bay-spacer-m3-6mm-v1.stl
hardware/makeyourpet-hexapod/Chipo/idler.stl
hardware/makeyourpet-hexapod/STEP/phone-bar.step
hardware/climbing-parts/component_plate.stl
hardware/climbing-parts/left-tibia-suction-exp.stl
hardware/climbing-parts/left-tibia-suction.stl
hardware/climbing-parts/p4-bay-v0/p4-bay-baseplate-v0.stl
hardware/climbing-parts/p4-bay-v0/p4-bay-cable-comb-v0.stl
hardware/climbing-parts/p4-bay-v0/p4-bay-deck-post-90mm-v0.stl
hardware/climbing-parts/p4-bay-v0/p4-bay-electrical-deck-v0.stl
hardware/climbing-parts/p4-bay-v0/p4-bay-fit-template-v0.stl
hardware/climbing-parts/p4-bay-v0/p4-bay-manifold-clip-v0.stl
hardware/climbing-parts/p4-bay-v0/p4-bay-pump-adapter-v0.stl
hardware/climbing-parts/p4-bay-v0/p4-bay-pump-pad-tpu-v0.stl
hardware/climbing-parts/p4-bay-v0/p4-bay-sensor-block-v0.stl
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

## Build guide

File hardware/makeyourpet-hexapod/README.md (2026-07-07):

##
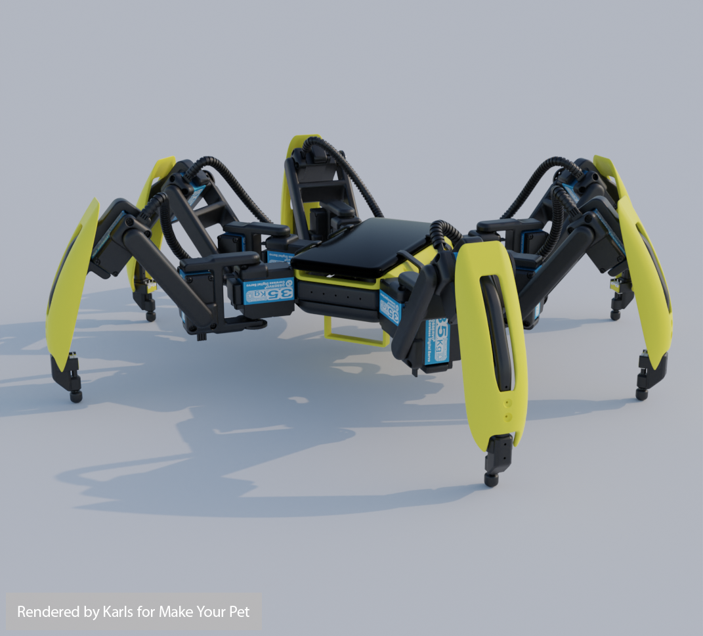
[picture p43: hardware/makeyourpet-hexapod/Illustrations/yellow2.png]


## Some quick links to get you started
- Watch the step by step build videos on my [YouTube channel](https://www.youtube.com/makeyourpet).<br>
- For build questions and to connect with the community join my [Discord server](https://discord.gg/vb8YWMfBuk).<br>
- A [wiring diagram](/wiring-diagram-servo2040.png) that you may find useful.<br>
- A fan-made [parts list](https://docs.google.com/spreadsheets/d/1jLi3IdmLERsBDhjaqHxFGQgZul_3uq9oj55M1rFG8mY/edit#gid=0). Also another fan-made [parts list](https://docs.google.com/spreadsheets/d/1y--z7EeejWcb-8ooPaIFn3Hulu9dJOcoKyGoxGq8KI8/edit?usp=drivesdk). And here is a [third one](https://github.com/LonelyGhost6/Public/blob/main/part-list.pdf). These are not meant to be a complete list of EVERYTHING that you need, but they cover most of the important and pricier stuff.<br>
- If you decide to use the Servo2040 board (highly recommended), find the [firmware](https://github.com/EddieCarrera/chica-servo2040-simpleDriver/releases/download/v0.0.1/chica-servo2040_release.uf2) and the [instructions on how to flash it](https://github.com/EddieCarrera/chica-servo2040-simpleDriver#loading-the-firmware-image) from Eddie's repository.<br>
  
## Illustrations
<p float="left">
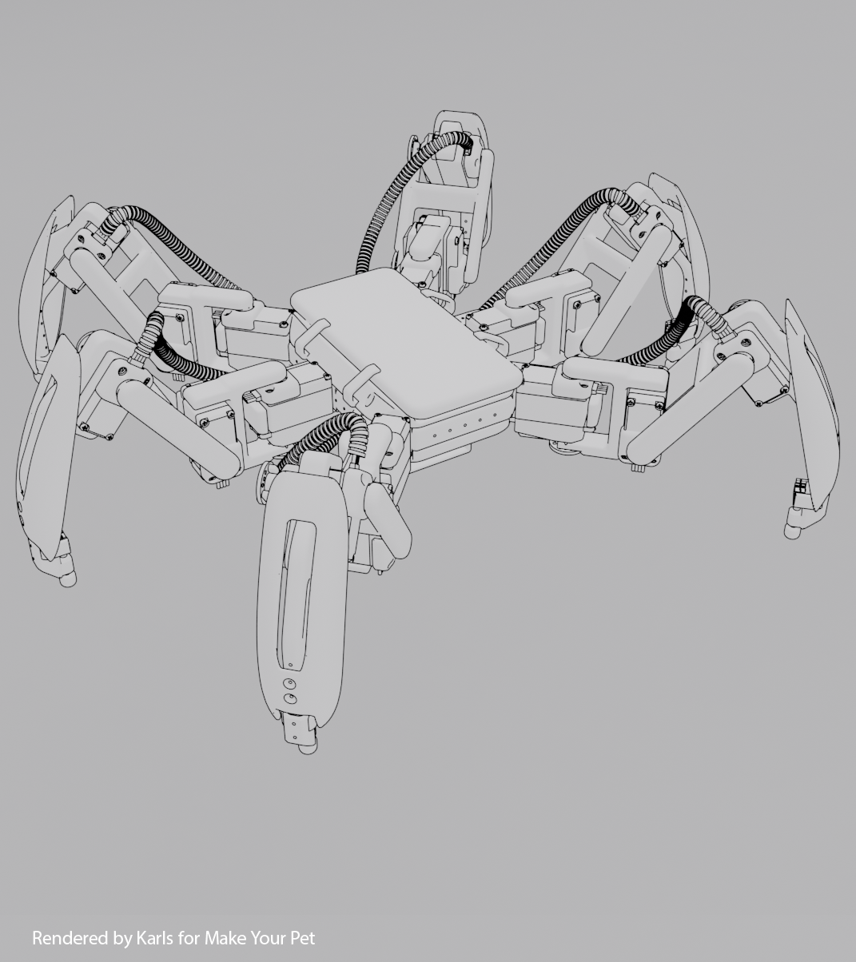
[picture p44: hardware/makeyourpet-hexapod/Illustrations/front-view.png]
  
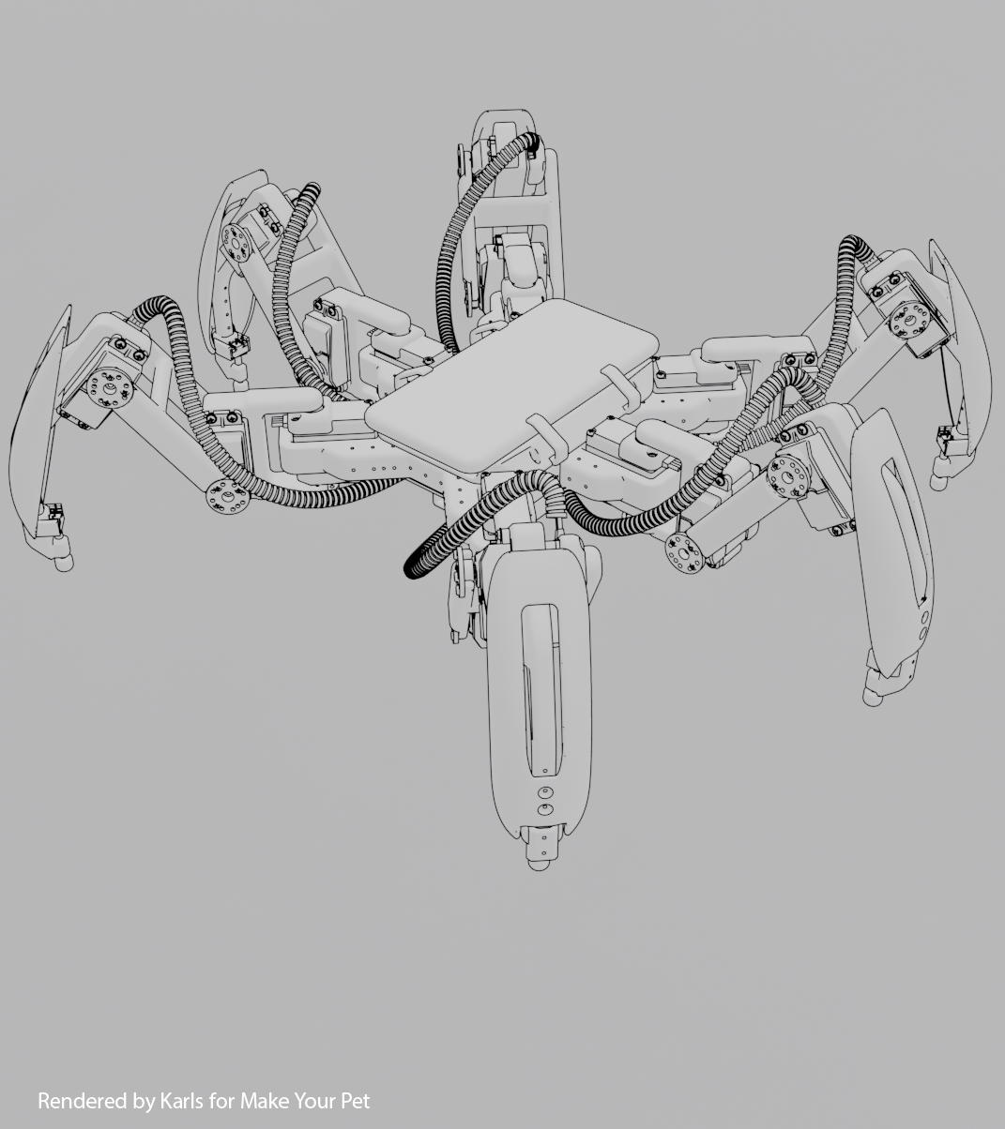
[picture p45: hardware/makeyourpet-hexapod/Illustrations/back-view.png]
  
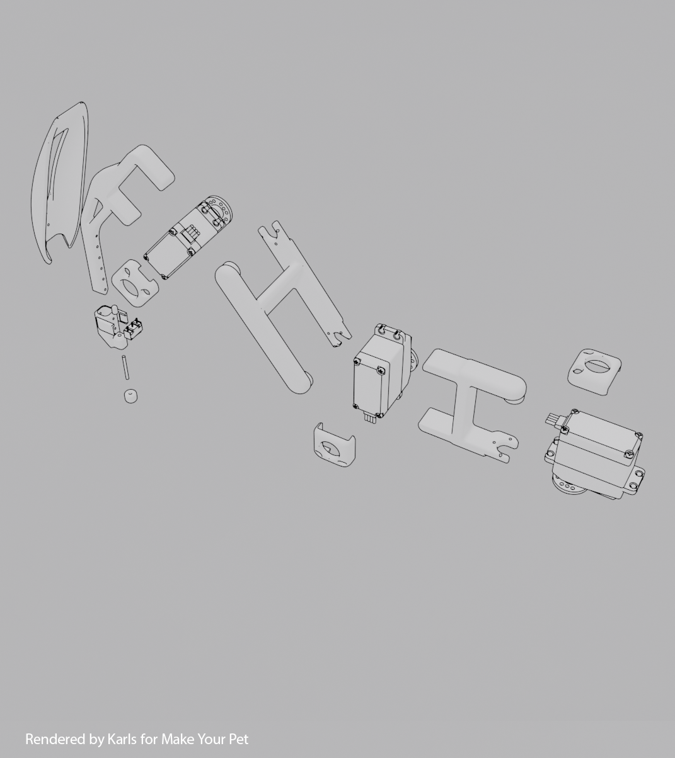
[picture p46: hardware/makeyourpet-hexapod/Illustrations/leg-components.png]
  
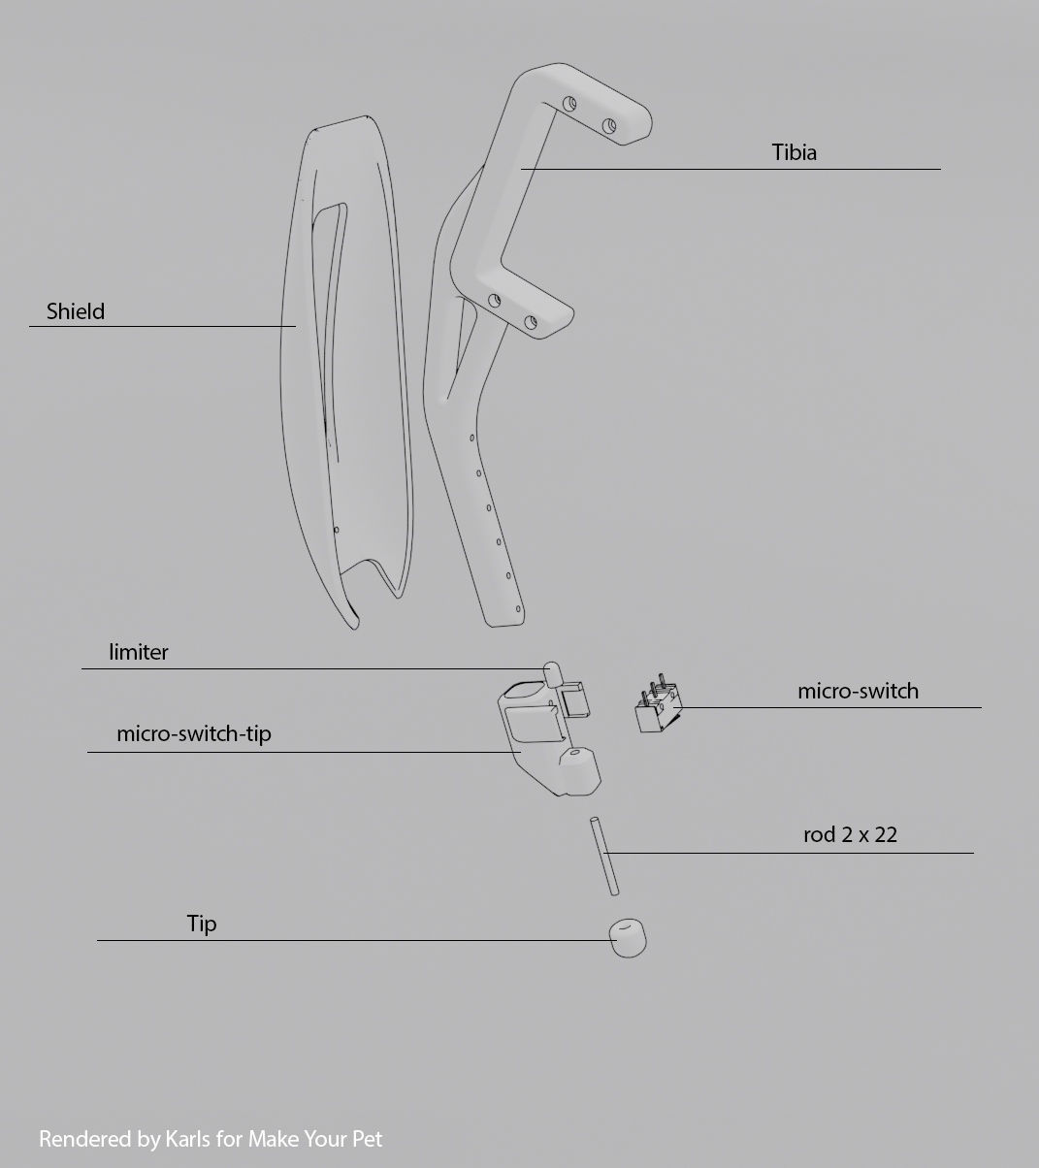
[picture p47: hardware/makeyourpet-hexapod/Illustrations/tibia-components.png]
  
</p>

## About the STL files in this repository
Some of the parts have multiple versions with slight differences. But all of them are compatible and should work.  
Make sure to check all of them to pick the one that works for you before committing to the print.  
I use the latest version of each part in my own hexapod, which is the one with the higher number at the end of its name.

## Compatible fan-made 3D printable parts
Check out [this](https://github.com/almelnz2005/hexapod) repository which contains modified (but compatible) versions of the original parts which uses metal horns, M3 screws and seperated components to make the parts more 3D printer friendly. This is especially helpful if you are printing with material other than PLA and have issues with supports or shrinking.

## Wiring Diagram
- Pimoroni Servo2040 (The newer, simpler, cheaper and recommended option):<br>
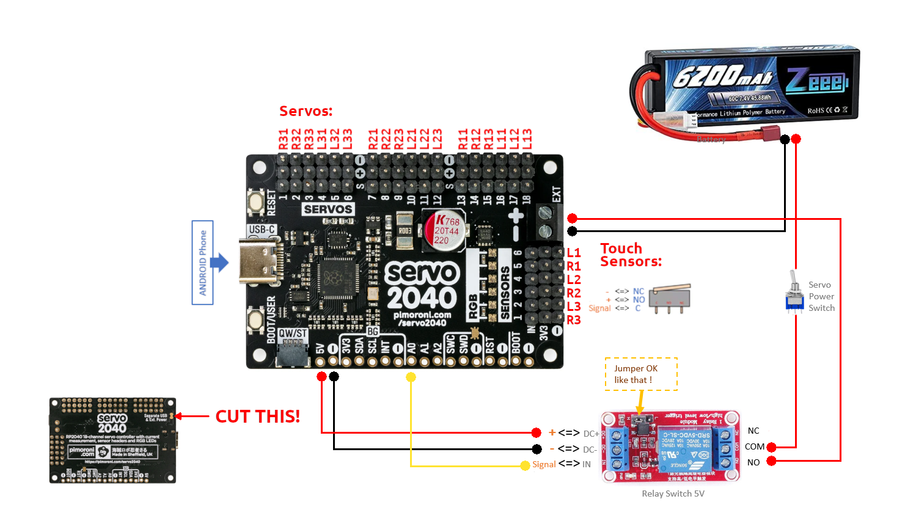
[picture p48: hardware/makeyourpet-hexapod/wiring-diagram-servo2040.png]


- Pololu Maestro (The original, complicated, expensive and legacy option):<br>
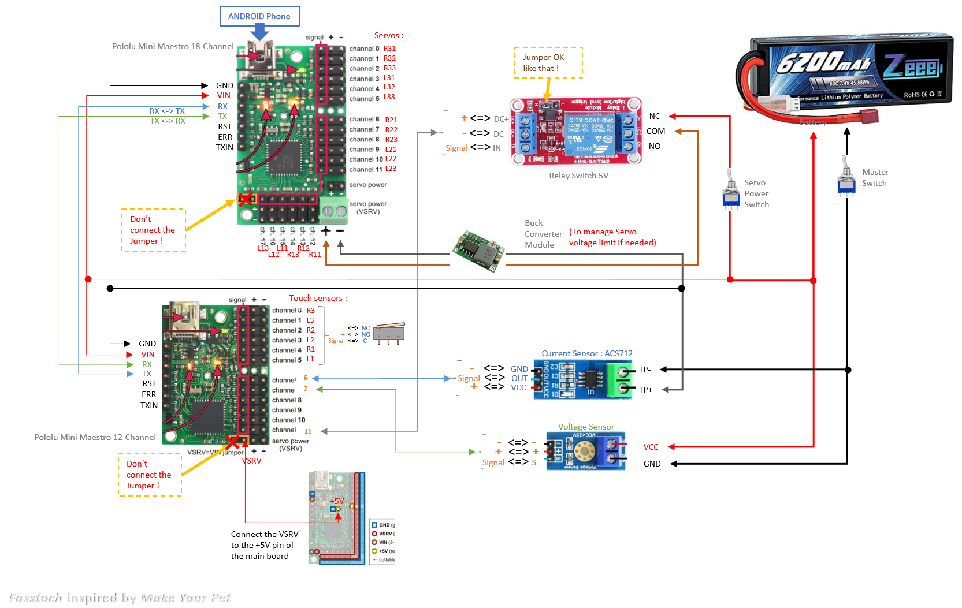
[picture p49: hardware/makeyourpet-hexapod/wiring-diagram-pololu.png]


## Electronic Component Layout
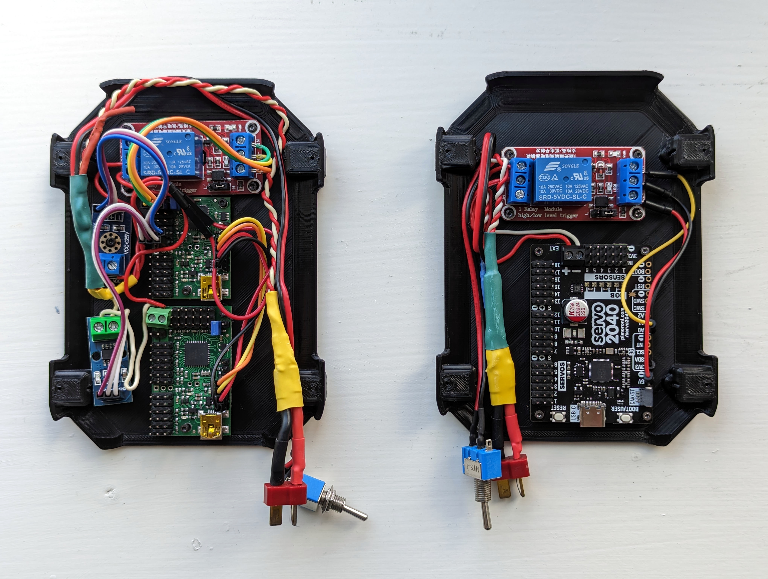
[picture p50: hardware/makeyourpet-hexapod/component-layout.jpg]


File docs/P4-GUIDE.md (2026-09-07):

# P4 整机爬墙集成 · 详细操作指南

目标（第 15~26 周）：**6 只吸盘足 + 全套气路上机，步态与吸附状态机联动，
在竖直玻璃/瓷砖墙上爬起来。**
验收（ROADMAP）：向上爬 1m、水平横移 0.5m、原地断电悬停 5 分钟不脱落；全程安全绳。
地-墙过渡本阶段**不做**：人工把机器人放上墙（过渡动作在 P5）。

本阶段两条线并行：**硬件线**（气动舱装配 + 气路 + 电气，依赖打印和到货）和
**软件线**（步态引擎改造 + 吸附联调，MockVacuumIO/MockDriver 上随时可以开工）。
软件线是本阶段真正的核心工作量，建议先动。

前置状态核对：

- [ ] P3 验收核对表全勾（直线 2m / 转 360° / 跨 2cm 障碍 / FK <5mm / 打印盘点）
- [ ] 全 18 路 ±45° 标定入 `config.py`（2026-08-08 ✅，含整机站立实机验证）
- [ ] 整机（无吸附）称重入 `weight-log.md`——**这项还空着，先补**；>2.2kg 即启动减重
- [ ] P4 气动舱 V1 已通过独立校验（`validate_p4_bay_v1.py` 22/22，见 P4-BAY-DESIGN §6）
- [ ] 储气罐到货（V1 罐抱箍等实物耳距，见 P4-BAY-DESIGN §4-11）
- [ ] Pi 环境正常：`pytest` 全绿、`get_throttled` = 0x0

---

## 第 0 步 · 先想清楚的三件事（影响后面所有工序）

**1. 步态引擎要做结构性改造，不是调参。** P3 的 `gait.py` 是纯开环相位表：
假定地面永远在 z0、触地精确发生在相位边界；触地瞬间垂直速度恰好最大
（默认参数 ≈170mm/s，"拍地"）；一过相位边界立刻横向拖脚。这三条对
"落脚即密封"全是反的。P4 要把它改成**事件驱动**：相位推进能被每条腿的
吸附事件暂停，摆动相收尾变成"减速竖直下探 → 压入 → 等真空确认"。
详见第 4 步。

**2. 吸附账要按实测重量重算。** P4-BAY-DESIGN §2.4 已泼过冷水：吸附系统
隐含预算 0.6kg，粗估 0.94~1.11kg，整机真实落点估计 2.6~2.8kg。单吸盘竖直
玻璃实测：法向拉脱 25N、剪切 15N（CLIMBING-DESIGN §漏项）。五足支撑剪切
承力 75N，对 2.8kg（28N）安全系数 ≈2.7——还活着，但每件到货必须称重记
`weight-log.md`，上墙前用实测整机重量把这笔账重新算一遍写进本文件验收表。
**09-04 回填**：整机（含吸附）实测 3537g = 34.7N；五足剪切 75N → 安全系数 **2.16**，坏一足四足 60N → **1.73**。实机已在此重量下完成全部上墙实验；结论见 `weight-log.md`。

**3. 舵机保护三原则**（P3 舵机讨论的结论，贯穿全部步态设计）：

| 原则 | 落实 |
|---|---|
| 瞬态外力可接受 | 偶发的吸附拽动、没压够重试，不用追求零外力 |
| **稳态对抗必须靠改指令消除** | PWM 舵机没有单路使能/力矩模式/位置回读，唯一手段是让指令跟着物理走（预压行程,第 4.2 节）；判据 = 吸附后总电流回落基线 |
| 绝不超堵转 | 35kg·cm 按 50% 降额（P2 实测口径）；步态宁慢勿快；使能中永远不许手掰 |

墙上与地面的本质区别：支撑足在墙上**持续**承剪切载荷（P2 实测单腿 hold
0.61A），五足支撑就是 ~3A 级持续电流 + 持续发热。这是常态不是异常——
`walk_teleop` 式的电压/电流状态行必须保留并加峰值/单足回落判据。

## 第 1 步 · 硬件线：气动舱首件与装配（1~2 周，与软件线并行）

按 P4-BAY-DESIGN §5.4 / §6.3 的顺序执行，此处只列核对项：

- [ ] `p4-bay-fit-template-v0` 上机，六腿全行程慢速摆动无干涉（动态扫掠，不可省）
- [ ] 泵适配板/阀轨/传感器桥/歧管卡逐件实物试插：可手装、无摇晃、不靠螺丝硬压
- [ ] 复核三件事：555 泵体相对支架孔的前后偏置、0520B 塑料嘴实际伸出量、打印孔径公差
- [ ] 储气罐到货：先单独抽 **-70kPa 压瘪测试**，再按实测耳距生成罐抱箍
- [ ] 电气甲板不通电预装全部 PCB，查端子/线弯/振动摆幅（V1 留了 10 个服务区）
- [ ] 整舱装配称重记 `weight-log.md`；**首飞单泵**（-130g），第二泵位留着
- [ ] 电池仍在腹面官方位（爬墙时腹面朝墙 = 重心离墙最近，P4-BAY-DESIGN §0-1）

连接拓扑照 `html/p4-system-diagram.html` / `html/p4-pneumatic-electrical.html`；
分压汇接板制作照 `html/p4-divider-board.html`；Pi 接线照 `html/p4-pi-wiring.html`。

走线纪律（P3 遗留，全部强制）：12V 功率线与模拟传感器线分梳；全舱禁面包板/
杜邦（震动间歇断连 = 状态机误判 = 坠落）；传感器线走 IDC 排线整体扣 Pi 40pin。

## 第 2 步 · 电气与 IO：`Pi5VacuumIO` 从 1 足扩到 6 足（2~3 天）

> **2026-08-14 软件侧完成**：下列 1~6 已全部落码进 `adhesion.py`（GPIO 表
> 08-14 点动实测过；7 路传感器映射照 p4_sensor_check；毛刺抑制改为时间窗
> 判据；罐压独立通道 + 出界判失效停泵置 `tank_fault`；仲裁位 `mode` 占位）。
> 待实机复核：整链 50Hz 主环耗时（ADS 已提到 860SPS + 0.05s 读数缓存）。

现在的 `adhesion.py` 是 P1 台架版：`VALVE_PINS = [5]`、单泵、单 ADS1115。P4 扩展：

1. **通道分配**：YYNMOS-8 恰好 8 路 = 6 阀 + 2 泵（首飞泵 2 路并定义、只接 1）。
   GPIO 引脚表定下来写进 `Pi5VacuumIO` 类常量，和 `config.py` 的腿序一一对应。
2. **压力 7 路**：2 块 ADS1115（0x48/0x49）共 8 通道，足压 ×6 + 罐压 ×1。
   足压传感器装**阀与吸盘之间（吸盘侧）**——阀关着也能读脚压，吸附确认和
   打嗝检测都靠它（P1 单传感器教训 + P2 打嗝实测 30s 进失控）。
   PGA 必须 ±4.096V（±2.048 在放气确认区间削顶,见 `adhesion.py` 注释）。
3. **逐路电学验证**（不接气路）：工具 `scripts/p4_sensor_check.py`，只读 I2C
   不碰 GPIO，所以气路和 MOSFET 板没装也能跑。不带参数出自检报告（8 通道
   逐路判定 + 大气点一致性 + 噪声），`--live` 吸气验证读取链路，`--wiggle N`
   抓瞬断（见下条）。阀侧另测：每路阀听得到吸合声、泵能起停。

   **2026-08-11 实测（六路足压，罐压/备用未接）**：大气点极差 12mV ≈ 0.3kPa、
   噪声 1.0mV ≈ 0.05kPa。偏差远小于 -30kPa 判据，**统一用 `V_ATM=4.486` 即可，
   不必逐只标定**（原计划的"7 只写成表"可省；真要标用 `--zero --save`）。

   量程方向以 P1 实测为准：**大气 4.5V、-100kPa 0.5V，分压后大气点 ADC ≈2.243V**。
   `html/p4-divider-board.html` 检验清单里"大气 ≈0.25V"那句写反了，按它核对会
   把好板子当坏的。未接的通道被下臂 10k 拉到地 ≈0V，据此和在线通道区分；
   第 8 路只留焊盘、没装分压，AIN 悬空读数飘属正常。

4. **毛刺抑制（新增，必做）**：状态机现在是单点判据——`adhesion.py` 里
   `read_foot_kpa(i) <= ATTACH_KPA` 一次读数就翻 ATTACHED。**改成连续 N 次
   采样都满足，或取中值滤波**；ATTACHED 漏气报警（压力回升 >10kPa）同样处理。

   理由：足压是判 ATTACHED 的唯一依据，一次假的深负压读数会让状态机误判该足
   已吸牢，于是放行抬起另一条腿，五足支撑变四足。判据必须扛得住单点毛刺。

   **2026-08-11 的一次误诊，流程记下来备用。** 症状：S7 碰一下读数就跳、
   过会儿又不跳；`--wiggle 7` 抓到 100 次"瞬断"。差点去拆焊点，实际结论是
   **人体静电耦合，板子完全没问题**。三步排除法：

   | 步骤 | 观察 | 结论 |
   |---|---|---|
   | `--wiggle` 看方向 | 正负严格交替、幅度对称 | 真瞬断是**单向**的（线断了分压点只被下臂拉向地），交替 = 围绕基线摆动，不是断连 |
   | `--scope` 看幅度 | 最大偏移仅 -2.8kPa | 真开路应冲到 **-112kPa**（满量程）。线要么断要么不断，不会"断一点点" |
   | 拆开「电」与「力」 | 塑料笔杆按压（只给力）无反应；放完静电轻触（只给电）复现 | 静电注入，非机械/压电 |

   决定性的一步是**对照另一路**：`--scope 2` 表现完全相同 → 板级共性，
   与 S7 的焊接无关。**任何单路怀疑，先测第二路做对照**，能省掉大量返工。

   飞行时电池供电、无人触碰，人体静电这条路径不存在，所以此现象对上墙无威胁。
   但它证明了一件真事：**分压节点确实对注入电荷敏感**——源阻抗 10k∥10k=5k，
   100nF 的转折频率 318Hz，只挡高频。飞行时的真正攻击者是**泵/阀开关瞬变和
   舵机电流冲击**，同样在低频段，所以第 3 步装完泵阀后必须复测（见下）。

   工具用法：`--wiggle N` 抓瞬断（会自动识别正负交替并提示改用 `--scope`），
   `--scope N` 出波形图 + 频谱，按"方向 + 幅度"定性——全单向且峰峰 >20kPa
   才是真瞬断，那时才按"传感器本体 → 根部出线 → 线束中段 → S 口接头 →
   敲焊点 → 掰板子"七步定位，修法是重压端子或直焊+热缩，**不是"再插一次"**。
   软件毛刺抑制是第二道防线，不能替代第一道。

5. **罐压通道的坑**：`read_tank_kpa()` 现在直接返回 `read_foot_kpa(0)`。储气罐
   没到货、S1 空着时该通道读 ≈0V，换算成 **-112kPa**，比 `PUMP_OFF_KPA=-65`
   还低 → 泵滞环认为罐内真空充足 → **泵永远不启动**。扩到 7 通道时一并修：
   罐压走独立通道号，并对"读数超出 -100~+10kPa 合理区间"判传感器失效报警。
6. **仲裁位**（远期双墙面混合足预留）：`AdhesionController` 的步态层接口里
   给每足留一个 `mode` 字段占位，本阶段恒为 `suction`，不实现任何逻辑。
7. 舵机总电高边继电器（切正极）**08-15 定案改由 Pi GPIO17（Pin11）驱动**，
   不再走 Servo2040 A0/GPIO26：模块跳线插 **H**（高电平吸合），线圈 DC+
   取 5V/5A 降压输出（与 Pi 同源，~100mA）、DC− 共地，IN1 ← GPIO17。
   `driver.enable()` 串口 RELAY 照发（保固件使能），功率通断由 GPIO17 收口。
   好处：chica 固件死机时 Pi 仍能独立断舵机电；Pi 进程退出/重启 GPIO 回
   输入态 → 继电器自动释放，天然急停兜底。断舵机电不影响 Pi 和气路——这是
   墙上急停的分级基础：先断舵机（常闭阀保真空，机器人挂住不掉），人再接。

## 第 3 步 · 气路装配与验漏（2~3 天）

链路（尾→前一条龙）：泵 → 单向阀 → 储气罐 → 罐口三通（罐压传感器）→
歧管（1 进 6 出）→ 6 × 常闭阀 → 三通取压（足压传感器）→ 过 coxa 服务环 → 吸盘。

- [ ] 全链路统一 4mm 宝塔 + 扎带，接头处环氧（不用热熔）
- [ ] 分段验漏：先"泵→罐"抽 -70kPa 保压，再逐足开阀验到吸盘（唇口按在玻璃上）
- [ ] 整链泄漏率复测（P1 口径：-40kPa 保持 >60s 不掉到 -20kPa）；
      **断电悬停 5 分钟的验收上限就由这条曲线决定**，不达标先治漏再往下走
- [ ] 每腿真空管过 coxa 关节留服务环（松弛圈），六腿全行程摆动不扯管
- [ ] 抽气时间实测：单足从贴壁到 -40kPa（P1 目标 <1s）；罐压恢复时间实测，
      决定是否上第二泵（判据：一个步态周期内罐压回到 PUMP_OFF 滞环带）
- [ ] **电磁兼容复测（泵阀装好后必做）**：`p4_sensor_check.py --scope N --secs 5`，
      期间让泵启停、六路阀逐个通断，看足压通道被污染多少。这才是真正要过的一关
      ——第 2 步测出的分压节点低频敏感性，在飞行时的攻击者就是这些开关瞬变。
      判据：干扰幅度必须远小于 -30kPa 的 ATTACH 判据（留一个数量级余量）。
      不达标的处理顺序：① 确认每只电磁阀有**续流二极管**（感性负载断电反峰
      可达数百伏，YYNMOS-8 一般自带，但要实物确认）→ ② 模拟线与 12V 功率线
      彻底分梳、必要时加屏蔽或双绞 → ③ 才考虑加大滤波电容。

## 第 4 步 · 软件线：步态引擎改造（本阶段核心工作量，2~3 周，Mock 上先行）

> **2026-08-14 实装回填**：本步 4.1~4.5 已全部落码——`hexapod/climb.py`
> (ClimbEngine，事件驱动分段摆动+相位暂停+互锁+重试+漏气冻结)、
> `config.py`（每腿 `press_delta_mm` + `climb_*` 参数组）、`adhesion.py`
> （判据时间窗防毛刺、is_leaking/leak_time、Pi5VacuumIO 七路传感器+罐压
> 失效判断、mode 仲裁位）。联调入口 `scripts/climb_walk.py`
> （--mock/--air/--release），可视化 `sim_walk.py --gait climb`。
> 语音壳 `scripts/voice_climb.py`（09-03）：climb_walk 原样跑在 pty 里，
> 语音映射成按键注入（急停"停下"→空格、"往前走"→w、"开始吸附/启动"→p、
> "单步/落地"→i、"冻结"→f），互锁与黑匣子全部照旧；退出/取机等放气类
> 只认键盘（详见 VOICE-GUIDE §3.9）。
> 4.6 之 1、2 已完成（37 pytest 全绿 + GIF 目检），3、4 待实机。
>
> **2026-08-16 落点几何修正（§4.3 实装，实机架空发现）**：默认站位
> reach=130 的压入位物理吸盘轴偏法线 ~21°（超 ±15° 容差，看着像
> "K→唇心连线垂直"）。ClimbEngine 现按 `cup_delta_deg=-25.2`（L3-DISPUTE
> 裁决口径）逐腿**解**"压入位吸盘轴⊥面"的站位半径（默认参数 ≈176mm，
> 触面瞬间偏角仅 1.2°），落点带按 ±12° 容差换算成半径区间裁剪；速度指令
> 整体限幅到 `climb_max_step=40`（吸住的脚不能滑，支撑相真实位移必须
> ≤ 步幅上限——这与 CLIMBING-DESIGN §6"reach 170 步幅 ≤40"处方吻合）。

### 4.1 摆动相从"一条曲线"改成分段状态机

每条腿的摆动相拆为（配合 `adhesion.py` 每足状态机）：

```
LIFT     通大气的同时抬离：足端目标沿面法向退开 ≥15mm（吸盘回弹行程 11~13mm
         会把脚顶回面上，必须边放气边走）
TRANSFER 平移到落点上方：沿用现有 smoothstep + 正弦抬腿形状
DESCEND  落点正上方竖直减速下探：XY 冻结，接近速度压到慢速（几十 mm/s 级，
         架空实测定值）——消灭现在"触地瞬间垂直速度最大"的拍地
PRESS    压入预压行程 press_delta（见 4.2）：XY 继续冻结，慢速；
         结束即 adhesion.request_attach(i) → PRESSING → SUCKING
WAIT     等 ATTACHED（-30kPa）；相位推进在此暂停，抽不上转 FAULT：
         抬 5mm 回 DESCEND 重试，连续 3 次失败 → 全机停走报警
LOAD     ATTACHED 后：足端目标切到压入后的位置保持（4.2），该腿转支撑相
```

支撑相和释放对称：重心先移走（该腿卸载）→ `request_release` → VENTING →
RELEASED → 才允许 LIFT。

### 4.2 预压行程与两态足端目标（消灭稳态对抗的关键）

§4.4 三态实测（LEG-GEOMETRY-OPEN.md）换算成步态参数：

| 状态 | h_cup | 含义 |
|---|---|---|
| 自由 | 19~21mm **按腿各测** | 摆动相几何，定案 l3=123.7 基于 L1 的 19 |
| 压到密封 | 7.5mm | **press_delta = h_cup_free − 7.5 ≈ 11.5~13.5mm** |
| 真空 -40~-50kPa | 8mm | 与密封态只差 0.5mm——**先压密封再抽气，抽气几乎不再动** |

实现口径：**不改动定案 `tibia_len=123.7`**，在 `config.py` 每腿新增
`press_delta_mm`，步态在触地点沿面法向加这个量作为压入段与吸附保持段的
足端目标。两态 l3 与"目标点加 delta"数学等价，后者不碰已定案的标定链。
（关联件：`workspace_analysis.py` 的 `CUP_DELTA=-25.2` 已按吸附态修订
——L3-DISPUTE 待办 g——落点带用它复核。）

**验收判据（每次实机跑都看）**：ATTACHED 并切换目标后 ~2s 内，总电流应
回落到接近该支撑构型的基线。某腿吸附后总电流持续多挂 ~0.6A = 该腿
press_delta 没吃干净（复测该腿 h_cup），舵机在和真空对抗。

### 4.3 落点与唇口姿态约束

- 唇口倾角容差 **±15°**（P1 台架实测）。3DOF 腿控制不了吸盘朝向——倾角由
  落点位置几何决定，所以这是**落点选择约束**（workspace 层），不是步态能
  逐步补的。平地/竖墙在设计站姿附近天然满足；落点带越界的步长直接拒绝。
- 压入方向沿面法向、XY 冻结是**步态硬规则**（4.1 已定），否则唇口蹭移密封失败。

### 4.4 触地判据

平面位置已知（地面/玻璃墙都是平的），主路线用**开环压入 + 电流监护**：
DESCEND 段按已知平面高度走到位再转 PRESS，全程盯总电流增量做两件事——
撞早预警（还没到预期高度电流就陡增 → 停）和触地确认。总电流分辨率
81mA/LSB，单腿压入增量百 mA 级可辨，阈值靠架空 vs 落地对比标定。
足压传感器是第二判据：PRESS 结束开阀后压力不降 = 唇口根本没贴上。

### 4.5 CLIMB 步态与安全互锁

- 用 `gait.py:29` 预留的 CLIMB（5/6 占空，wave 相位，一次一腿）。三角步态
  两腿组同时吸放，泵和时序都紧张，爬墙不用。
- 互锁（比 `adhesion.py` 注释的 ≥4 更严，首爬用严的）：**抬任一足前，其余
  5 足全部 ATTACHED**；相邻足不同时释放（CLIMBING-DESIGN §漏项约束）。
- ATTACHED 漏气报警（压力回升 >10kPa）：该足立即重抽挽救；挽救 2s 无效 →
  全机冻结当前姿态 + 报警（五足里坏一足还有 4 足,安全系数按 09-04 实测 3.54kg 为 1.73）。
- 泵滞环 -60/-75kPa（2026-08-17 从 -55/-65 加深：带宽 10→15 拉长补抽间隔，
  整体更深加吸附余量）。⚠ -75 顶着 555 泵标称极限下限（-75~-85），且每足
  单向阀装机后盘压下限 = 泵极限 + 阀开启压差——须实测盘压 plateau 过 -75
  才算数，过不了泵永不停机，双线一起回调到 plateau 浅侧 ≥5kPa 处。
  步态周期先放到 3~4s（cycle_time 可调），跑顺再提速。
- 下滑补偿（`climb_sag_comp_mm` / `--sag-comp`，默认 0=关，2026-08-17 上墙
  实测后加）：竖墙实测"每抬一腿整机被拽下一截"——载荷从 6 足重分配到 5 足，
  弹性让位（波纹盘横向变形 + 舵机载荷让位角）被下一次吸附锁死成棘轮，
  6 次/周期能吃掉整个步幅 = 原地踏步。补偿在每次抬腿事件的 LIFT+TRANSFER
  段（摆动足离面、没有盘在压入）把全部支撑足沿身体系"下坡"方向（头朝上
  贴墙 = -X，随积分航向旋转）额外匀速平移设定量，把身体顶回去。每事件
  实际量 = min(设定, (40−半步幅)/5)：支撑尾端总外摆超 40mm 后腿出 IK 包络
  （满速 4mm 封顶，降速走步幅缩小、限额自动放宽）；目标出工作空间时
  climb_walk 有降落伞——冻结悬停，不让异常炸控制环。标定口径：先白板笔在
  支撑盘旁点标记走 3 周期分清损失类型——**标记不动而身体下沉 = 弹性棘轮
  （可补）；标记跟着盘走 = 界面滑移（补不回，查清洁/盘压）**。确认弹性型
  后从 2~3mm 起步逐次加，盯每周期净位移，取实测下沉量八成以内。⚠ 超过
  真实下沉的部分会把吸附中的盘沿面往下坡拖，宁欠勿过。

### 4.6 开发顺序（全部先在 Mock 上）

1. `MockVacuumIO + MockDriver` 联跑新步态状态机，pytest 补用例：正常循环、
   SUCKING 超时重试、ATTACHED 漏气、互锁拒抬；
2. `sim_walk.py` 出 GIF 目检摆动相分段轨迹（竖直下探段看得见）;
3. 实机架空：六腿空走 CLIMB 步态 + 阀/泵真动作（吸盘悬空必然 FAULT，
   正好验证重试和互锁路径）；
4. 地面玻璃板：进第 5 步。

## 第 5 步 · 地面吸附行走——时序总装验收（1 周）

水平玻璃板（垫实、擦净）上跑完整"压-抽-确认-走-放"步态。这一步验证的
是**时序**，风险为零（掉不下去），必须在上墙前把以下全部打勾：

- [ ] 连续 20 步无 FAULT（或 FAULT 全部自动重试成功）
- [ ] 每步吸附后总电流回落基线（4.2 判据），无持续对抗腿
- [ ] 抽气时间/罐压恢复满足步态周期（不满足：放慢周期或上第二泵）
- [ ] 释放侧无"顶脚"现象（LIFT 边放气边退的时序对了）
- [ ] 走停 10 分钟，无舵机烫手（对抗已消、载荷正常的旁证）

## 第 6 步 · 上墙：斜面递进 → 竖直（1~2 周）

姿态原则：身体贴近墙面（重心距墙越近，上排吸盘剥离力矩越小,ROADMAP 已定）。

| 级 | 面 | 通过标准 |
|---|---|---|
| 1 | 30° 斜玻璃 | 上爬 0.5m,无 FAULT 级联 |
| 2 | 60° 斜玻璃 | 上爬 0.5m + 静停 1 分钟 |
| 3 | 竖直,离地 0.3m 起 | 上爬 0.5m |
| 4 | 竖直 | **验收:上爬 1m、横移 0.5m** |
| 5 | 竖直 | **验收:断电悬停 5 分钟**(断舵机电+泵电,常闭阀保真空;人在旁待接) |

每级全程安全绳（顶部打点,登山辅绳留轻微余量,打点先做承重测试）、地面垫子。
横移和上爬用同一步态引擎,只是速度向量不同——CLIMB 步态本身无方向性。

## 第 7 步 · 收尾归档

- [x] 整机（含吸附）称重入 `weight-log.md`,对照 2.5kg 上限写结论——09-04 实测 **3537g**，超上限 1037g，结论与待定项见 weight-log
- [x] 吸附账按实测重量重算,数字写进本文件（第 0 步之 2 的回填）——安全系数 2.16（五足）/ 1.73（四足），已回填
- [ ] 各腿 press_delta / h_cup 实测值入 `config.py` 并注日期
- [ ] 泄漏率、抽气时间、断电悬停实测曲线存 `docs/data/`
- [ ] P5 遗留清单:地-墙过渡、负重、双泵决定、双墙面仲裁位启用

## 常见问题

| 症状 | 处理 |
|---|---|
| 某腿 SUCKING 频繁超时 | 按序查:唇口倾角(落点在工作带边缘?)→ press_delta(该腿 h_cup 实测过没?)→ 该路气管/三通泄漏 → 唇口酒精清洁 |
| 吸附后总电流不回落 | press_delta 没吃干净,舵机对抗真空;复测该腿两态 h_cup(杯批次差 2mm,别用 L1 的值套全部) |
| 打嗝(足压周期性回升又抽回) | P2 老对手:微泄漏。唇口清洁、检查该足吸盘座密封;打嗝超 30s 按失控处理(P2 实测教训) |
| 某路足压偶发跳变/碰线就跳 | **别急着判接触不良**(2026-08-11 差点误诊)。按序：① `--scope N` 看形状,真瞬断是单向台阶且冲到 -112kPa 附近,双向尖峰/几 kPa 都不是;② 对照测另一路,一样跳 = 板级共性不是本路问题;③ 塑料笔杆按压 vs 放静电后轻触,分开「力」和「电」。确属瞬断再用 `--wiggle N` 七步定位,修法是重压端子或直焊+热缩 |
| 泵/阀一动就冻结 IO 持续失败(Errno 121) | ADS1115 被 12V 开关瞬态干失联(08-23 实测:三次 121 全落在泵/阀通电后 0.05~0.6s 内、均 <1s 自愈、IO错计数全场 0=芯片失联前健康;TLM 电压平稳没用——那是舵机母线,看不见 12V/3.3V 瞬态)。软件已有 0.5s 容忍+重试骑过毛刺;复发查硬件:①泵/阀续流二极管 ②ADC 分压板供电去耦(100nF+10µF)与地线拓扑(别与泵电流共走) ③I2C 线离 12V 束、加绞地 ④电池充满(升压板输入越低开关瞬态越凶,7.72V 起跑那次就炸,8.03V 那次没事) |
| 罐压跟不上步频 | 先放慢 cycle_time,再上第二泵;泵一直响不停 = 系统性泄漏,回第 3 步验漏 |
| LIFT 时脚被"粘"在面上拖 | 放气没到位就抬(VENT_TIME/RELEASE_KPA 判据没等到)或该路阀排气堵 |
| 地面 walk_teleop 抬腿幅度极低、吸盘不离地(装气路后才有) | 不是重量:阀断电=通罐位,吸盘经每足单向阀接歧管,身体一压把空气挤进歧管、抬腿时单向阀不让回流→被动真空锁脚(30mm 盘约 -40~-60kPa≈30~40N,超 femur 足端拉力)。walk_teleop/voice_teleop `--vent auto`(默认):站起/走动时六阀通电排气,停走落稳 0.5s 断电(站着不耗六线圈≈25W),起步串行上电约 1s 内脚不抬;`on` 常通;`off` 不碰阀做对照(v 键轮换);同类不跑吸附状态机又要抬腿的地面脚本同坑 |
| 墙上原地踏步(每抬一腿整机下滑一截) | 先分清损失在哪:玻璃上支撑盘旁点标记走 3 周期——标记不动而身体下沉=弹性棘轮:08-20 量化 83% 的下滑在放气密封破裂一瞬(慢放气无效),首选 `--handover`(vent 前零力交接,起标=实测单次弹跳×0.8,docs/HANDOVER-DESIGN.md,body_lean 原地 A/B 标定 δ);`--sag-comp` 是坠后追补的治标层(§4.5),与交接 A/B 期只开一个;标记跟着盘位移=界面滑移,酒精清洁玻璃+唇口,盯状态行"盘差"(盘压压不进 -75 泵不停=真空浅,法向力和横向刚度都打折);无罐模式吸附慢、蠕变时间占比高,装罐后会明显好转 |
| 抬脚瞬间整机晃动 | 释放前重心没移够,该腿还承着载;检查支撑多边形计算 |
| 走几步某舵机烫 | 墙上持续载荷是常态,但单腿明显更烫 = 承载不均或残余对抗;对照电流曲线找腿 |
| 墙上 Pi 重启 | 欠压=坠机级事故。立即停,查 5V 独立供电与 `get_throttled`,修好前不上墙 |
| 启动时阀线圈逐一亮起后整机死机(灯绿→红常亮、SSH 失联,概率性) | **09-03 实机定案(lean_20260903_135325.log):扳机是舵机继电器合闸,不是阀**——六线圈逐一通电全程 5V 平稳 4.88~4.89V、thr=0x0,`舵机继电器已合闸` 是最后一行,<50ms 后死机。红灯常亮=Pi 5 的 PMIC 把 SoC 断电的停机态(同 `halt` 后,要重新上电)。根因是余量:Pi 5V 输入空载只有 4.89V(正常降压应 5.05~5.15,`get_throttled=0` 看不出这种没过线但没余量),18 舵机同刻上电把共用的 2S 电池一拽就过线。治本在供电:在 Pi USB-C 端带载量、降压输出调到 5.1~5.2V;USB-C 线换短粗;降压输入/输出端各并 ≥1000µF 电解;核对舵机回流地直接回电池负极、不绕 Servo2040 的 USB 地。软件缓解(已做):`enable(True)` 拆两步——合继电器(带电不出力)→0.4s→固件使能(出力),黑匣子两段各自采母线(`合闸后 x s`/`使能后 x s`),下次再死能分清是带电冲击还是出力冲击。取证工具:一次性 `bash scripts/pi_forensics.sh setup`(内核日志落盘,须在死机**之前**跑),复现后重新上电 `pi_forensics.sh check`;黑匣子 `TLM 电源 5V=…` 每 0.1s 一行(`vcgencmd pmic_read_adc`,用户须在 video 组)。Pi 5 无 RTC 电池,开机列表里的起始时刻是上次存盘的假时钟(可差几小时),`check` 会用最后一条日志的真时间倒推真实开机时刻。**09-04 追加**:降压换成可调模块调到 5.19V(PMIC 读 5.105V,已到官方电源水平)后 walk_teleop 启动仍死机(当时 walk_teleop 没黑匣子,已补齐,tag=walk/voice)——静态电压不是根因,是合闸瞬间毫秒级以下的跌落/地弹,10Hz 采样与万用表都看不见;`/proc/device-tree/chosen/power/power_reset`=2 两次都读到,当时按树莓派工程师说法当作上次开机被 PMIC 因低压断电的口供;**09-06 对照:正常 poweroff/reboot 几次后仍读 2,本机上无区分力,不算证据**(死后红灯常亮本身已说明 SoC 被 PMIC 断电,内核崩溃灯不会变红)。电池是 2S 航模锂电无保护板,不存在过流跳保护,电池塌陷不是主嫌;**09-04 晚定案(案卷 `html/pi-crash-ground-loop-20260904.html`)**:①用户发现每跑一次 walk_teleop 粘滞位必从 0x0 变 0x50000,即使没死——偶发致命事件有了确定的非致命替身,实验判据改为"置不置";②walk_20260904_215456.log:GPIO17 拉高后 14ms thr=0x50005,此时舵机母线 0.00A;使能后 6.67A、电池 7.71→7.31V,Pi 5V 纹丝不动——不是舵机大电流,是合闸瞬间;③A/B 同一次开机只用 GPIO17 脚本合闸:拔掉 Pi↔Servo2040 USB 线十次全 0x0,插回第一次即 0x50000——**路径=USB 地环路**;④新降压是 XL4015 5A CC/CV 板,背面 R050 低边检流电阻串在 Pi 的地回路里、合闸瞬间蓝灯闪绿=模块自己也看见了这股脉冲(加重因素,旧固定模块无此电阻也死,非根因)。机理:触点闭合对 18 舵机+Servo2040 电容充电的百微秒几十安脉冲在舵机回流地上造成压差,一部分经 USB 地→Pi 地平面→GND 杜邦线→R050 回电池负极,杜邦线+R050 压降在 PMIC 眼里就是 5V 跌落。治法(待装机,判据仍是粘滞位):USB 隔离器(ADuM3160 类全速)最干净;舵机轨预充软启动(小继电器串 4.7Ω 5W 先合 100ms,或 P-MOS 软启动;10Ω 跨触点手动预充可先验证);星形地只能减轻。Pi 5V 并电容只治标(2200µF 按 0.7A 扛 0.4V 约 1ms)。**09-06 续篇(案卷 08 节)**:装 ADuM3160 隔离器后 GPIO17 十次合闸全 0x0,USB 路径确认切断,但 body_lean 仍死在合闸后几十 ms(lean_20260906_234509.log 最后一行"已合闸",合闸后 0.05s 采样没来);孤岛测试:断电松开降压板 IN−,Pi GND 与电池负极不通→Pi 侧只靠降压板一根线连电池侧,地环路不是唯一入口(YYNMOS-8 IN−/DC− 光耦隔离已在气电页实测);剩余入口=降压板本身:XL4015 模块要求输入≥输出+1.5V=6.7V,2S 阀负载下 7.70V/舵机使能后 7.31V 余量不到 1V,合闸脉冲(30A×30mΩ≈0.9V 起)一拽就塌;只合闸(阀不通电)十次干净、真实脚本(六阀已通电)必死,差别正是阀负载先把电池压低一截;治=换低压差同步降压(输入 6V 出头仍稳 5.1V、≥5A、压差<0.5V)或升降压,隔离器保留,预充退为次要,输入并电容+肖特基不推荐;换件后用真实脚本多跑,判据粘滞位不置+不死;**09-07 软件止血**:四个启动脚本加 `--relay-first`,串口一开就合闸(六阀线圈还没通电,电池只带 Pi),固件使能仍在阀之后;换降压板前先用它跑,也是 A/B:前置后仍死,"阀负载吃掉余量"就不成立;**09-07 结果**:relay-first 首跑(body_lean --no-tank)即死在合闸后几十 ms(末行 0.452s"已合闸",阀线圈未通电,5V 5.101V,串口刚开 0.25s),"阀负载吃掉余量"撤回,扳机=合闸本身;隔离器后只合闸脚本 1 死/11、真实脚本 3 死/3,剩余差别=串口开着+Pi 自身负载(电源监视子进程/每行 fsync);下一步充电宝给 Pi 单独供电跑三次定案(母线读数来自 Servo2040 经串口,Pi 侧可整体悬浮不接地线):活=入口是 Pi 的 5V 来源→买低压差同步降压,死=与传导供电无关→首嫌串口链路,再做只合闸脚本+开串口对照;**09-07 晚定位**:Pi 改充电宝单独供电(继电器线圈侧 DC+/DC− 须改接 Pi 排针 5V/GND,接在降压 OUT± 上时 IN1 无回路、继电器不动),其余不动,合闸不再死(次数/粘滞位读数待补)→入口=Pi 的 5V 来源(XL4015 在 2S 上无余量),串口链路与 Pi 自身负载排除;机理(脉冲拽电池→降压输入跌破 6.7V→输出塌→PMIC 断电)仍是推断,坐实需示波器同看降压输入/输出;治=换低压差同步降压/升降压,或 Pi 独立小电池;结论修订史四次(power_reset 撤证、XL4015 8V→压差 1.5V、一条路径→两条入口、阀负载撤回)均被对照实验推翻,现结论同样待示波器复核;**09-07 晚满电对照**:电池充满、Pi 接回 XL4015、其余不动,真实脚本站起成功,get_throttled=0x0(连曾欠压都没置)——同一块降压板电池 7.3~7.9V 三死三、满电 0x0,入口钉在电池→降压板→Pi 这条路,串口链路排除;充电宝那组已确认:继电器线圈侧改接 Pi 排针 5V/GND(Pi 侧与电池侧零导线),真实脚本跑过、不死,次数/粘滞位未记;接回电池后 Pi 5V/GND 与继电器 DC+/DC− 一起接降压 OUT±;满电不是治法,一场跑下来电池掉回 7.6V 就回必死区,换件前开机先量电池,<8.0V 别启动 |
| 阀通电反而吸不住 | 常闭阀口接反(进/出/排气三口)或 `VALVE_ON_LEVEL` 电平反 |
| 断电悬停掉压快 | 逐段验漏定位;接头补环氧;唇口清洁;罐容量复核 |

## 安全

- **安全绳全程不摘**,包括斜面级;打点先做人力冲坠测试;绳留轻微余量不影响步态。
- 垫子铺满作业面正下方;首爬高度 0.3m。
- 断电悬停测试人站机器旁,手虚扶不接触。
- 舵机使能中不许手掰任何关节(35kg·cm 打齿);调整姿势先断舵机电——
  常闭阀会保持吸附,机器人不会掉。
- 墙上任何异常(打嗝、FAULT 级联、异响、烫)先冻结姿态观察,不要急着继续走;
  吸附态冻结是安全态,乱动才危险。
- 锂电规矩同 P0~P3:充电不离人、XT60 随手可拔、先断电再改线。

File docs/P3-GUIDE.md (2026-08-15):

# P3 整机装配与地面行走 · 详细操作指南

目标（第 9~15 周）：**装配 18 舵机整机，完成全舵机标定，在平地上走起来。**
验收：平地直线行走 2m、原地转 360°、跨过 2cm 障碍、单腿 FK/IK 点到点误差 <5mm；
整机称重记入 `weight-log.md`（无吸附系统 ≤1.9kg 参考线，超 2.2kg 启动减重）。

P2 决策门已于 **2026-07-22 通过**（验收数据见 `P2-GUIDE.md` 核对表下方）。
本阶段两条线并行：**快递线**（第 1 步下单，等货 1~2 周）和**打印线**（第 2 步，
把打印机排满）。装配（第 3 步起）等两条线汇合后开始。

前置状态核对：

- [ ] P2 决策门通过（2026-07-22 ✅）
- [ ] Pi 5 环境正常：`pytest tests/` 全绿、`get_throttled` = 0x0、独立 5V/5A 供电
- [ ] L1 腿标定值在 `config.py`（tibia 89.3 k基准 / femur 49.7 / coxa 官方 -8 待 P3 实测）

---

## 第 0 步 · 一个必须先想清楚的构型问题（半小时，影响打印清单）

ROADMAP 的分阶段设定是：**P3 地面行走用标准小腿**（left/right-tibia + 足底开关 +
橡胶足尖），**P4 才换吸盘小腿上墙**（"6 只吸盘足上机"）。但这带来两个代价：

1. **L1 现在装的是吸盘小腿**（P2 用的、已标定）。按 ROADMAP 走，P3 要把它换成
   标准小腿——换结构件 = tibia 标定作废，P4 换回来还要再标一次。
2. 全部 6 条腿的 tibia 标定在 P4 换吸盘小腿时**全部作废重做**。

两条路线：

| 路线 | 内容 | 代价 | 收益 |
|---|---|---|---|
| **A · 按 ROADMAP** | 6 条腿全用标准小腿 + micro-switch-tip + 橡胶足尖 | 多打 6 个标准小腿（小件，~13g/个）；tibia 标定 P3/P4 各做一遍 | 足底开关触地检测（官方成熟路线）；吸盘唇口不磨地 |
| **B · 直接吸盘小腿** | 6 条腿直接装吸盘小腿走地面 | 无触地开关（吸盘小腿末端是吸盘腔，没有开关位）；唇口当脚掌磨地（吸盘是 ¥5~15 耗材，备了 8 个） | tibia 只标一次；L1 标定不作废；P4 不用再换件 |
| **B 需要正视的问题** | 足底开关 BOM 里标注"爬墙步态刚需"，但吸盘小腿本来就没有开关位——**P4 无论如何要靠压力传感器做触地/吸附确认**。开关其实只服务 P3 | | |

**✅ 已定路线 B（2026-07-22）**：6 条腿直接装吸盘小腿走地面。P3 验收里的
"触地检测步态"降级为开环三角步态 + 压力/电流兜底（已记入验收核对表）；
足底开关仍随第二批购入，留 P4 实验。

> **✅ 吸盘小腿已定版（2026-07-27）**：采用 `left-tibia-suction.stl`，配套
> `suction-foot-door.stl`；不采用带触地环的 `*-exp.stl` 试验版。右腿版
> `right-tibia-suction.stl` 已按官方左右小腿相同方式镜像生成，可以开始打印。

## 第 1 步 · 下单第二批（当天做，快递是关键路径）

按 `BOM.md`"第二批"（约 ¥1100~1900）：

| 类 | 内容 | 备注 |
|---|---|---|
| 舵机 | DS3235 35kg 180° ×16（凑 18+2 备） | 别买杂牌最低价，爬墙堵转是常态 |
| 平台件 | 足底开关 ×6+备（路线 B 也买，¥5 的事，留 P4 实验）、M1.6×6 ×120 等螺丝、定位销、橡胶足尖 | 螺丝数量按官方 fan parts list 核对 |
| 吸附系统 | 泵 ×1（凑双泵）、常闭阀 ×6+2 备、吸盘 ×5（凑 8）、**XGZP6847A ×6**（凑 7 = 每足 1 + 罐 1）、ADS1115 ×1（凑 2 块共 8 通道，I2C 0x48/0x49）、**真空歧管 1 进 6 出 ×1**（`气动歧管 4mm 一进六出`，~¥10-20；BOM 原清单漏项——别用三通串链凑，15 个插接点 vs 7 个，接点=泄漏点。市售歧管进口多为 8mm **快插**——快插夹不住软硅胶管，把快插拧下换 G1/8→4mm 宝塔直通，全链路统一 4mm 宝塔+扎带；或买 `鱼缸气盘 一进六出` 无调节阀直通型，宝塔嘴原生配 4mm 软管，到手先抽 -70kPa 验漏）、4mm 三通 ≥7（足压传感器取压用）、储气罐（首选`汽车真空罐`塑料款 ~¥30,为负压设计免压瘪测试、自带宝塔嘴和安装耳;备选 `DIY CO2 瓶盖 双头`纯双通版+碳酸瓶 ~¥5,到手 -70kPa 验漏）、安全绳 | **阀必须常闭**，下单前问清。足压传感器装**阀与吸盘之间**（吸盘侧），阀关着也能读脚压——吸附确认/打嗝检测都靠它（P1 单传感器教训 + P2 打嗝实测 30s 进失控） |
| 电源 | XL6009 ×1（凑 2，BOM 第二批枚举漏项）；**舵机电源开关 ×1**（持续 ≥15A、3.3V 触发；首选 `30A 继电器模块 5V 光耦` 低电平触发版，或 15A MOS 模块 ×2 并联） | 12V 泵/阀供电；开关控舵机总电，**切正极高边**（地经 USB 共通,低边会被旁路；控制脚原定 Servo2040 A0,P4 08-15 改 Pi GPIO17,见 P4-GUIDE）。规格依据 P2 实测:整机持续 2~4A/瞬态 ~12A。到手三查:IN 悬空=断、3.3V=通、释放=断 |
| 耗材 | PLA/PETG 补到 2kg 库存；硅胶管盘余量不足补 5m；扎带/环氧胶/热缩管自查；**分压汇接板料**：10k 电阻 ×14+、100nF ×7、洞洞板小块、JST-XH 或焊线；**P4 接线料**：2×20 IDC 排线压接头+排线 ×1（整体扣 Pi 40pin,替代单根杜邦）、JST-XH 带线成品端子若干（免压线钳） | 打印线开跑前确认；气路密封用环氧不用热熔。P1/P2 面包板上的传感器分压（10k/10k）P4 必须移到焊接洞洞板——面包板/杜邦震动下间歇断连=状态机误判=坠落风险；ADS1115 3.3V 供电、PGA 必须 ±4.096V（±2.048 会在 -10kPa~0 削顶,放气确认失效）。**分压板制作图纸（原理图/洞洞板布局/装配检验）见 `html/p4-divider-board.html`** |

## 第 2 步 · 打印排程与库存盘点（与快递并行，P2 遗留项）

打印顺序按"最长的先打"。库存表（打完/过检就划勾，过检 = 装配孔能穿丝、
舵盘位吻合、无翘边分层）：

| 件 | 需要 | 已有 | 还差 | 说明 |
|---|---|---|---|---|
| frame | 1 | 0 | 1 | **最大件,第一个上机打** |
| left-coxa2 / right-coxa2 | 3 / 3 | 1（L1） | 2 / 3 | 同名多版本取编号最大 |
| left-femur / right-femur | 3 / 3 | 1（L1） | 2 / 3 | PLA 4 壁 40% 填充 |
| left-tibia-suction | 3 | 1（L1） | 2 | **PETG 立打**：吸盘腔朝下,5~6 壁 45%,brim ≥8mm（README 打印说明） |
| right-tibia-suction | 3 | 0 | 3 | **PETG 立打**；已由定版左腿沿 XZ 平面镜像生成，配同款门盖 |
| suction-foot-door | 6+2 备 | 1（L1） | 7 | 平躺无支撑 |
| top-cover4 / bottom-cover | 各 1 | 0 | 各 1 | bottom-cover 与 -flat 二选一,按电池布局 |
| shield、servo2040-bottom-cover、battery-bar | 各 1 | 0 | 各 1 | 小件见缝插针 |
| 备件 | coxa/femur/tibia 各 +1 | | | 摔机快修用,最后打 |
| **P4 气动舱固定件** | 1 套 | 0 | 1 套 | **第二批到货后实测尺寸再设计**（扩展 generate_climbing_parts.py）：泵 TPU 软固定（隔膜泵震动,硬锁会松螺丝+毛刺读数）、6 阀阵列梁、PET 罐抱箍（罐先单独抽 -70kPa 做压瘪测试）、7 路压力传感器位 + 感测三通（每足支管引回舱）、PCB 柱、理线梳;整舱做成可拆模块,大质量件贴机身平面摊平（重心距墙）;每腿真空管过 coxa 关节留服务环。**电气+气路连接拓扑见 `html/p4-system-diagram.html`** |

`right-tibia-suction.stl` 由 `tools/generate_climbing_parts.py` 正式生成：对定版
`left-tibia-suction.stl` 的参数化几何做 `Y → -Y` 镜像，与官方
`left-tibia.stl` / `right-tibia.stl` 的左右变换一致。吸盘腔、六角袋和螺丝位
随主体镜像；门盖自身关于中心面对称，左右腿共用 `suction-foot-door.stl`。

**每打完一批就称重记 `weight-log.md`**：P2 的全部验收建立在"整机 2.5kg"上，
1.8 倍余量里最大的变数就是超重（分析见 P2 验收讨论）。结构件全齐时小计一次，
预估整机（+18 舵机约 60g×18=1.1kg +电池 ~350g +板/线）是否压得住 1.9kg。

## 第 3 步 · 装配（快递到货后，3~5 天）

1. 顺序照官方 YouTube 装配视频（频道 MakeYourPet），接线照
   `hardware/makeyourpet-hexapod/wiring-diagram-servo2040.png`，通道映射在 `config.py`。
2. **装舵盘规矩**：先 `python scripts/servo_center.py` 全舵机回中再装舵盘。
   注意：servo_center 发 1500µs，而标定基准点是 1510µs（`(1040+1980)/2`，
   §4.6）——装舵盘用 1500 没问题（花键一齿 ~14°，远粗于 1°），但**后续量
   attach_deg 时必须用 `servo_calib_helper.py` 发 1510**。
3. **舵机使能状态下永远不许手掰**——35kg·cm 堵转打齿，且掰出来的角度是假的。
4. 供电老规矩：Pi 独立 5V/5A，绝不与舵机共轨；舵机 7.4V 经继电器（当时定
   Servo2040 A0/GPIO26，P4 08-15 改 Pi GPIO17）；装完 `vcgencmd get_throttled`
   必须 0x0。
5. 走线时给 P4 留量：每条腿根部预留真空软管的走线通道和扎带位（现在不接管，
   但线束别把路堵死）。

## 第 4 步 · 全舵机标定（装配后必做，2~3 天，最费事的工序）

顺序有讲究（`LEG-GEOMETRY-OPEN.md` §5 剩余主线）：

1. **coxa γ（装机身后第一件事）**：用基线法——L1↔R1 舵盘螺丝投点连线为基准，
   不依赖"机身口袋对准 55°"（§5 主线 1，方法图见标定参考图 §05）。
   L1 的 coxa 一直用官方 -8 凑合，现在终于能实测了。
2. 每关节 ±45° 脉宽：手动（发脉宽,不是手掰）摆到 -45°/+45°，记录填
   `config.py` 的 `us_m45/us_p45`；方向反的 `sign=-1`。
3. femur/tibia `attach_deg` 逐腿实测：照 L1 的成熟方法（femur 高差法 §2.12、
   tibia 三边法 §2.11）。**未实测的腿沿用官方 68 有 §2.9 的 44° 基准风险，
   六条腿全要实测，别偷懒。**
4. **端到端 FK 抽查（P3 验收项）**：每腿发一组关节角，卷尺量足端实际位置 vs
   `leg_fk` 预测，**<5mm 通过**。L1 顺带裁决 §4.4 记录的 tibia_len 116 vs 120
   之争（4.6mm 张力正好在判据边上，量三个不同姿态取多数）。
5. 规矩重申：换结构件/重装舵盘 → 该关节标定作废重做。

## 第 5 步 · 软件上手与站立（1~2 天）

```bash
pytest tests/                                  # 先全绿
python scripts/sim_walk.py --gif walk.gif      # 仿真步态目检
python scripts/stand_up.py                     # 站立 + 传感器读数
python scripts/walk_teleop.py                  # wasd/qe 遥控，1/2 切三角/波浪
```

- **stand_up 前把机身垫高架空**：任何脚本退出/异常都会断舵机电，机器人会趴下。
- 第一次站立盯三件事：18 路无异响/无发烫、电流读数合理、`get_throttled` 仍 0x0。
- 架空状态 walk_teleop 空走确认相位正确（三角步态同组三条腿同起同落），再落地。

## 第 6 步 · 分级验收（1~2 天）

| 级 | 内容 | 通过标准 |
|---|---|---|
| 1 | 架空空走 | 步态相位正确、无关节抖振 |
| 2 | 落地站立 60s | 无过热、无欠压、姿态不塌 |
| 3 | 直线 2m | 不跑偏出 0.3m 走廊、不摔 |
| 4 | 原地转 360° | 完成即过 |
| 5 | 跨 2cm 障碍 | 完成即过 |
| 6 | FK 抽查 | 六腿全部 <5mm（第 4 步已做，这里归档数据） |
| 7 | 称重 | 整机（无吸附）实测记 `weight-log.md`；>2.2kg 启动减重 |

**P3 验收核对表**：

- [ ] 直线 2m / 转 360° / 跨 2cm 障碍
- [ ] 六腿 FK 抽查 <5mm，tibia_len 116/120 之争裁决并回写 config
- [ ] 全 18 路标定值入 `config.py`（含 coxa γ 实测，终结官方 -8）
- [ ] 整机重量入 `weight-log.md`（≤2.2kg；超了列减重清单）
- [ ] 整机结构件打印盘点完成（第 2 步表格全勾）
- [ ] 触地检测：路线 A 开关实装 / 路线 B 记录降级决定与 P4 压力方案

## 常见问题

| 症状 | 处理 |
|---|---|
| 站立时某腿姿态明显不对 | 先查 sign 再查 attach_deg;某关节差 ~14° 的倍数 = 舵盘装错齿 |
| 行走跑偏 | 步态本身左右对称(零标定误差=零漂移),跑偏来自 attach 残差和支撑相打滑。**灵敏度**:任一路 attach 差 1° → 偏航 0.5~0.8°/m、横移 3~17mm/m;杠杆最大的是中腿 L2/R2 的 tibia(0.81°/m)和 femur(0.60°/m),中腿 coxa 几乎无影响(误差被吸收成相位偏移)。按现有残差量级,2m 偏 2~6cm 属正常。先直行 2m 分清**偏航**(航向变了)还是**横移**(航向没变、整体平移),再决定复测哪路;不想再拧标定就把实测值填进 `config.py` 的 `yaw_trim_deg_per_m` / `side_trim_mm_per_m`(向左为正,只在有 vx 时按比例生效) |
| 走几步后舵机烫 | 站姿关节角别贴行程边缘;步态放慢(SPEED 调低);检查是否某腿承重远大于其他 |
| Pi 重启 | 欠压。`get_throttled` 非 0 → 供电问题,先修再继续,这在 P4 是掉落事故 |
| 舵机偶发抖振 | 信号线与舵机电源线捆太近;分开走线或加磁环 |
| 步态相位乱 | 通道映射错位,`config.py` 对照接线逐路核 |

## 安全

- 落地测试前全部架空跑通;初次落地在软垫上。
- 舵机使能中不许手掰任何关节;调整姿势先断使能。
- 锂电规矩同 P0~P2:充电不离人、XT60 随手可拔、先断电再改线。
- 摔机快修:备件腿常备(第 2 步最后一批),摔坏当天能换。

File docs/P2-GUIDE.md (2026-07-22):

# P2 单腿爬墙试验 · 详细操作指南

目标（第 5~9 周）：**整个项目的决策门——一条腿在竖直玻璃前自动完成
"伸腿 → 压紧 → 抽气 → 压力确认 → 承力 → 放气 → 抬腿"循环，并独立撑住 1.5kg 配重。**
本阶段结束时你应该能拍出两段视频：①连跑 50 次吸放循环的台架；②滑车锁销拔掉后，
1.5kg 配重完全挂在吸附的腿上 5 分钟纹丝不动。

通过之前**不买第二批器件**。顺序建议：第 1 步（备料）先行；第 4 步（软件干跑）不依赖
台架，等快递期间就能做完；第 2~3 步搭台，第 5~6 步是正戏，严格按序。

前置状态核对（都是 P0/P1 已完成项，缺一个先回去补）：

- [ ] L1 腿 ±45° 脉宽 + `attach_deg` 实测值已入 `config.py`（tibia 89.3——新吸盘件
      2026-07-19 复测，方向亦对调；femur 49.7，见 `LEG-GEOMETRY-OPEN.md` §2.11/§2.12；
      coxa 用官方 -8 即可，本台架不敏感，见第 2 步。⚠ 换结构件/重装舵盘后标定作废重做）
- [ ] `Pi5VacuumIO` 实装且 P1 三条曲线达标（<1s 到 -40kPa；60s 泄漏不过 -20；释放 <0.5s）
- [ ] 吸盘已装进 `left-tibia-suction.stl` 腔体、门盖已粘，整足挂重复测通过（P1 第 9 步）

---

## 第 1 步 · 备料（1~2 天，多为身边材料）

| # | 材料 | 规格/数量 | 说明 |
|---|---|---|---|
| 1 | 竖直玻璃板 | ≥400×400mm，厚≥5mm | 背面全程衬木板；边缘贴胶带防崩边 |
| 2 | 立柱与底座 | 2020 铝型材或木方 | 底座要压重物或 G 形夹夹在桌上 |
| 3 | 抽屉滑轨（三节） | 300mm、标称承重≥10kg | 或直线导轨；要求竖直装、滑动顺滑无旷量 |
| 4 | 滑车板 | 木板/亚克力 ~150×100 | 装在滑轨动侧，腿根座和配重都上它 |
| 5 | 锁销 | 门插销 1 个 | 滑车"锁死/解锁"两态切换，必须单手可拔 |
| 6 | 配重 | 凑总滑动质量 1.5kg | 含滑车板+腿+座；用水瓶/杠铃片微调 |
| 7 | 弹簧秤 | 0~5kg | 侧向 1kg 拉力验收用 |
| 8 | 缓冲垫 | 毛巾/EVA 垫 | 滑轨行程下端，脱吸坠落缓冲 |
| 9 | 斜撑角码、螺丝 | 若干 | 刚性是本台架成败的一半 |

## 第 2 步 · 台架几何（半天~1 天）

```
        立柱(竖直)                玻璃(竖直,背衬板)
          │ ┌滑轨                    ║
          │ │┌滑车板──coxa舵机壳═══╗  ║   coxa 输出轴水平、垂直指向玻璃
          │ ││   +配重      femur ╲ ║
          │ ││锁销↕                ╲║ ← 吸盘压在玻璃上
          │ ││                 tibia║
          ┴─┴┴──缓冲垫──────────────║──
```

1. **玻璃竖直**、擦净（酒精），背面衬板夹紧。
2. **coxa 舵机壳固定在滑车板上**：输出轴水平、垂直指向玻璃；
   壳安装面（相当于整机的机身平面）**距玻璃 90mm**。座上开长槽做 ±20mm 可调。
   > 为什么是 90 而不是 ROADMAP 里写的"约 130"：130 是标定前拿"足端工作半径"凑的
   > 粗值；按实测标定 + 物理吸盘轴（δ=22.7°，见第 4 步）重算（`CLIMBING-DESIGN.md`
   > §6 A 表），站高 90mm、支撑相 reach 170mm 时吸盘轴偏角仅 1.6°。
   > 本指南的 90mm 为准，脚本第 4 步的常量按它算好了。
3. **腿平面竖直**：coxa 回中（1510µs）时，femur/tibia 的摆动平面应铅垂
   （目测+手机水平仪贴 femur 侧面即可，±3° 无所谓）。
4. **coxa 没标定不影响本台架**：coxa 轴⊥玻璃，γ 偏差只是让足端沿玻璃面转过一段弧，
   吸盘轴相对玻璃法线的姿态完全不变（这正是把 γ 实测推迟到 P3 的依据，
   `LEG-GEOMETRY-OPEN.md` §5）。腿偏着伸出去别扭的话，微调 `config.py`
   coxa `attach_deg` 把它扶正，数值不用精确。
5. **刚性验收**：手推腿根，任何方向晃动 <1mm。压紧反力是几十牛级别，
   支架软了预压行程会被变形吃掉，吸不住的第一嫌疑人就是它。
6. **几何自检**（先别装玻璃）：跑第 4 步的 `--mock` 确认软件后，真机发 press 姿态，
   卡尺量吸盘唇口平面到"玻璃将要安装的平面"——唇口应**越过**该平面约 15mm
   （这就是压紧过盈）。差得多就动长槽调 90mm 那个距离。

## 第 3 步 · 滑车承力机构（半天）

1. 滑轨竖直装立柱上，滑车行程 ≥50mm，下端放缓冲垫。
2. 腿根座+配重全部装滑车板上，**总滑动质量称到 1.5kg**（≈ 整机 2.5kg ÷ 3 只
   有效承力足，加余量）。配重尽量压在滑轨轴线上，偏了会卡轨。
3. 锁销两个状态：**锁死**（滑车固定 = 刚性台架，跑循环用）/
   **解锁**（滑车自由下滑 = 配重全部转移到吸附的腿上，承力验收用）。
4. 演练一次"单手拔销、单手上销"，拔销时另一只手不碰滑车。
5. 脱吸演练（无腿空滑车）：解锁让滑车自由落到缓冲垫，确认行程末端不撞坏东西。

## 第 4 步 · 软件与干跑（等台架期间做完）

软件交付物已就位：`software/scripts/single_leg_wall.py`。

**几何常量**（脚本开头，按第 2 步的 90mm 台架算好）：

| 常量 | 值 | 含义 |
|---|---|---|
| `FOOT_X` | 169 | 足端径向位置：压紧时**物理吸盘轴**⊥玻璃（偏 0.1°） |
| `Z_LIFT` | -70 | 抬离位，唇口离玻璃 20mm |
| `Z_CONTACT` | -90 | 唇口刚触玻璃（= 髋平面距玻璃距离） |
| `Z_PRESS` | -105 | 压紧位 = 触壁再进 15mm（预压行程 13.5 + 预载 1.5，`LEG-GEOMETRY-OPEN.md` §4.4 实测） |

> ⚠ **FOOT_X 为什么是 169 而不是"K→P 垂直玻璃"的 122**：物理吸盘轴沿方轴方向，
> 与模型虚拟线 K→P 差固定 **δ=22.7°**（膝轴 K 不在方轴上，`LEG-GEOMETRY-OPEN.md`
> §2.13）。按 K→P⊥玻璃（122）去压，吸盘会以 22.5° 斜角怼玻璃，超 15° 容差直接吸不住。
> 台架图：见 `html/p2-rig-diagram.html`。

台架距离不是 90 时改常量速查（H = 壳安装面到玻璃实测值）：
`Z_CONTACT=-H`、`Z_PRESS=-H-15`、`Z_LIFT=-H+20`；`FOOT_X`：H=80→168、90→169、100→169。
整个循环内物理吸盘轴偏离玻璃法线 ≤4.5°，在 P1 实测的 15° 容差内，行程余量 ≥44°。

1. **mock 干跑**（开发机或 Pi 都行）：
   ```bash
   cd ~/spider/software && source .venv/bin/activate
   python scripts/single_leg_wall.py --mock --cycles 3
   # 期望：3 个循环全部成功，保持期压力 -40kPa 左右，成功率 100%
   ```
2. **参数**：`--cycles N` 循环数；`--hold 秒` 每循环吸附保持时长；`--csv 路径` 明细
   （20Hz 的 t/cycle/phase/kpa/amp，压力曲线和舵机电流都在里面）；`--release` 善后。
3. **失败重试**已内建：SUCKING 超时 → 抬 5mm → 重新压紧，最多 3 次，全败记该循环失败。
4. **Ctrl-C 是"冻结"不是"停止"**：阀保持当前状态、舵机保持使能——吸附中的滑车
   不能因为你按了 Ctrl-C 就掉下来。善后固定跑：
   ```bash
   python scripts/single_leg_wall.py --release    # 放气 + 回抬离位
   ```
5. **泵策略**：脚本屏蔽了状态机的泵滞环（P1 单传感器下罐压读数失准会让泵长转发热），
   改为"抽气前预抽 1.5s + 吸附保持期低于 -45kPa 补抽"。泵占空比因此很低，
   50 循环连跑不担心过热。
6. 真机首跑前把 P0 的老规矩过一遍：跳线已割、电池极性、`get_throttled` = 0x0。

## 第 5 步 · 分级上量（1~2 天）

每级通过再进下一级，任何一级不过先解决再前进：

| 级 | 状态 | 命令/操作 | 通过标准 |
|---|---|---|---|
| 1 | 锁死 + 无配重 | `--cycles 1 --hold 3` | 一次成功；屏幕吸附时间 ≈ P1 的 <1s |
| 2 | 同上 | `--cycles 10` | 成功率 10/10（允许内建重试） |
| 3 | 锁死 + 配重上滑车 | `--cycles 5` | 结构无变形、成功率不降 |
| 4 | **解锁承力** | `--hold 300` 单循环，屏幕确认吸附后手动拔销 | 1.5kg 悬挂 5 分钟不脱落，压力稳定 |
| 5 | 侧向载荷 | 承力状态下弹簧秤水平拉滑车至 1kg，保持 10s | 不脱落、不滑移 |
| 6 | 力矩余量 | 看 CSV：压紧瞬间电流峰值 vs 保持期基线 | 峰值有肉眼余量；把 `Z_PRESS` 再加深 3mm 复测电流增幅做参照 |

- 第 4 级操作纪律：**屏幕没显示吸附确认（≤-30kPa）绝不拔销**；拔销后人站侧面；
  重新上销后才允许放气。
- 第 6 级说明：Servo2040 读的是全板总电流，是近似值——看的是相对变化不是绝对值。
  35kg·cm 舵机按 50% 降额的判断标准：加深 3mm 预压后电流增幅仍平缓（没有陡增/异响/
  发烫），即认为墙面姿态有余量；陡增说明已接近堵转区。

## 第 6 步 · 验收 50 循环与决策（半天）

```bash
mkdir -p ~/spider/docs/data
python scripts/single_leg_wall.py --cycles 50 --hold 5 --csv ~/spider/docs/data/p2_50cycles.csv
```

带配重、滑车锁死连跑（承力项已在第 5 步单独验收过）；跑完抽 5 个循环手动解锁复验承力。

**P2 验收核对表（决策门）**：

- [x] 连续 50 次吸放循环成功率 >95% —— **100%（50/50，零重试）**，2026-07-22，`docs/data/p2_50cycles.csv`
- [x] 吸附状态下滑车 1.5kg 悬挂 5 分钟不脱落 —— 压力全程 [-81, -55] kPa，约 4 次补抽，无打嗝，`docs/data/p2_1_5_kg_hold300s.csv`
- [x] 承力状态下 1kg 侧向拉力不脱落、不滑移（2026-07-22 实测通过）
- [x] 压力曲线 + 舵机电流 CSV 归档进 `docs/data/`，力矩余量结论见下
- [x] 台架照片/视频存档（`images/p2_wall_suck.mp4`、`images/suck_wall.jpg` 等）
- [ ] 整机结构件打印进度盘点（P1/P2 期间打印机空闲时段的产出）——移至 P3 期间进行，与第二批快递并行

**验收数据摘要（2026-07-22，决策门通过）**：

| 项 | 实测 |
|---|---|
| 50 循环成功率 | 100%（零重试）；各循环 hold 最差压力 -69.7~-71.3 kPa |
| press→hold 耗时 | 中位 2.74s，最长 2.77s（50 循环高度一致） |
| 1.5kg×300s 悬挂 | 压力全程未高于 -55（补抽带 -55/-65 生效，~75s 补一次）；挂重后剪力拉伸波纹，真空被动加深至 -81 |
| **力矩余量结论** | press 峰值 0.73A vs 空载基线 0.07A、hold 基线 0.16A——峰值仅为瞬态且绝对值低，余量充足。挂重 hold 期持续 0.61A（峰 0.90A）为舵机对抗真空收拢力+配重的持续载荷，300s 无异响/过热，可接受；P3 整机需注意此持续项 ×3 足 |
| 已知遗留 | 吸附瞬间脚被真空拽向墙数 mm（波纹吸扁），几何无害（轴偏 <0.2°），暂忽略；P3 步态需容忍此扰动 |
| 泄漏教训 | 2026-07-22 曾在补抽带 -50/-60 下于 -53 附近泄漏失控打嗝至 -17——泄漏随真空变弱指数加速，补抽带已改 -55/-65 并加打嗝报警（升过 -30 蜂鸣） |

**决策**：

- **通过** → 下单第二批（`BOM.md`：15 个舵机 + 其余全部）→ 进 P3（地面行走）。
  P3 装机身后第一件标定的事就是 coxa γ（方法：`LEG-GEOMETRY-OPEN.md` §5 主线 1）。
- **不通过** → 升级 40mm 吸盘（法向力 ×1.8）/ 双头泵并联重测；仍不通过 → 项目方案
  重估，此时只花了第一批的小几百块。

## 常见问题

| 症状 | 处理 |
|---|---|
| SUCKING 全超时，重试 3 次全败 | 罐没抽起来（听泵声、查 12V）；预压不足——量第 2 步几何自检那 15mm 过盈；玻璃或唇口脏 |
| 压紧时舵机嗡嗡响、电流大 | H 距离量错导致 press 过深；支架变形吃预压（回第 2 步刚性验收）；`Z_PRESS` 临时改浅 3mm 定位问题 |
| 吸附成功但拔销就掉 | 真空度贴着 -30 线过的——查泄漏（P1 曲线 2 复测）；把脚本判据从 -30 收紧到 -40 再验 |
| 滑车解锁后不下滑（假承力） | 滑轨卡滞/配重偏置卡轨——空滑车复演第 3 步第 5 条 |
| 承力时缓慢滑移 | 剪切贴边缘了：玻璃重新酒精擦；真空度提到 -50 以下；仍滑就是 30mm 吸盘剪切极限，考虑 40mm |
| 循环成功率在 90% 附近晃 | 逐条看 CSV 失败循环的压力曲线：抽不下去=密封问题（几何/清洁），抽下去又回升=泄漏 |
| 电流列恒定不变 | mock 下固定 1.0 属正常；真机检查是不是没接舵机电源 |
| Ctrl-C 后想继续 | 先 `--release` 善后回到已知状态，再重新起 `--cycles` |
| 吸附中断电了会怎样 | 取决于 P1 第 3 步实测的阀断电行为；"断电≠保持"的阀会直接放气掉落——测试中途不要动电源 |

## 安全

- **滑车和配重下方任何时候不放手脚**，缓冲垫全程在位；解锁承力时人站台架侧面。
- 吸附确认（屏幕 ≤-30kPa）之前绝不拔锁销；放气之前必须先上销。
- 玻璃背面衬板、边缘贴胶带；挂重和侧拉时戴护目镜（吸盘崩脱会弹）。
- Ctrl-C 不放气是刻意设计——善后只用 `--release`，不要直接拔舵机电。
- 12V/锂电规矩同 P0/P1：先断电再改线、充电不离人、XT60 快断随手可拔。

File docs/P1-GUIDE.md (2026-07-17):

# P1 吸附系统台架验证 · 详细操作指南

目标（第 2~5 周）：**在工作台上把"泵 → 罐 → 阀 → 吸盘 + 传感器 → Pi"整条真空链路调通，
拿到爬墙可行性的第一批实测数据。**
本阶段结束时你应该能拍出一段视频：竖直玻璃上单吸盘足挂着 3kg 配重纹丝不动，
SSH 进 Pi 敲一条命令，完成一个"吸-确认-放"循环（<2s）。

顺序建议：第 1 步不依赖气路件，舵机装好就能做；第 3~7 步严格按序（每步是下一步的前提）；
第 8~9 步是产出数据的正戏。

---

## 第 1 步 · 单腿 ±45° 脉宽标定（等气路件期间做完）

P2 的 `single_leg_wall.py` 要做单腿 IK，L1 腿（通道 15/16/17）的标定是前提。
流程见 `software/README.md`"标定流程"，这里补充台架细节：

1. **舵机供电电压**再确认一次：不得超过舵机标签上限（6.8V 版必须经降压给 6.0~6.5V，
   不能 2S 直连）。
2. 逐关节找 -45°/+45° 的实际脉宽，两个方法选一：
   - **方法 A（不拆结构，推荐）**：手机水平仪贴在腿段上。先回中记下基准角，
     然后微调脉宽直到腿段相对基准转过 ±45°。俯仰关节（femur/tibia）用水平仪，
     水平摆动的 coxa 用垫在下面的纸打印量角器。
   - **方法 B（更准，费事）**：拆下腿段打印件，舵盘装 P0 打印的 `calibration-arm`，
     配 `calibration-ruler` 按官方视频用法找 ±45° 刻度。
   微调脉宽用 python 交互：
   ```bash
   cd ~/spider/software && source .venv/bin/activate && python
   >>> from hexapod.driver import Servo2040Driver
   >>> d = Servo2040Driver(); d.set_all_pulses_us([1500]*18); d.enable(True)
   >>> d.set_pulses_us(16, [1520])   # femur=16，±10µs 一步慢慢逼近
   ```
3. 实测值填入 `config.py` L1 的 `us_m45/us_p45`；方向反了改 `sign=-1`，
   零位残差微调 `attach_deg`。改完 `pytest tests/` 必须仍然全绿。
4. 复核：命令 femur 到 0°、+45°，水平仪实测误差 <2° 即合格。

## 第 2 步 · 气路件到货核验（到货当天）

| 器件 | 核对项 |
|---|---|
| 二位三通电磁阀 | 12V、"常闭"标称——真实行为第 3 步实测，别只信页面 |
| 30mm 波纹吸盘 | 金具是 **M5 通孔**（气从螺柱中心走）+ 90° 弯头宝塔，缺一样 `suction_foot` 装不了 |
| XGZP6847A | **模拟输出版**（3 线：5V/GND/Vout），不是 I2C 版；量程 0~-100kPa |
| 555 双头泵 | 12V、标称极限 ≤-75kPa；两个抽气头，可三通并联提速 |
| 单向阀 | 壳体有流向箭头 |
| 8 路 MOSFET 板 | 触发电平兼容 3.3V（光耦版看说明，"高电平触发 3-24V"即可） |
| XL6009 | 可调版（带电位器） |

## 第 3 步 · 电磁阀特性实测（半小时，决定接法、软件极性和一个设计假设）

设计文档假设"常闭阀断电 = 吸盘保持真空"（`CLIMBING-DESIGN.md` §2 的被动安全设计）。
但市售 0520B 类"常闭"三通阀不少是**断电时出气口通大气**——真是这样的话断电悬停
不成立。这一步就是把买到的阀摸清楚：

1. 万用表量线圈电阻（几十 Ω 正常），12V 上电听到"咔哒"说明线圈工作。
2. **吹气法**测通断：三个气口分别标 P（接罐/真空侧）、A（接吸盘侧）、R（排气口）。
   断电状态和通电状态下，分别往每个口吹气，记录哪两个口连通：

   | 状态 | 实测连通关系 |
   |---|---|
   | 断电 | ___ ↔ ___ |
   | 通电 | ___ ↔ ___ |

3. 对照结论：
   - **理想**（断电 A↔P 或 A 全封闭）：断电保持真空成立，按此接管。
   - **常见**（断电 A↔R 通大气）：P1 台架不受影响照常做（数据测试时阀保持通电即可），
     但要把实测结果记进 `CLIMBING-DESIGN.md` §4——P4 前必须解决
     （换"断电保持"接法的阀型，或修改断电悬停的安全论证）。
4. 无论哪种，写下"**吸盘接通真空**对应线圈通电还是断电"——第 7 步 `VALVE_ON_LEVEL`
   常量由它决定。

## 第 4 步 · 12V 供电与 MOSFET 驱动链路（半天）

1. **XL6009 调压**：输入接 2S 电池（接前万用表确认极性），**空载**电位器调到输出
   12.0V，再接负载。P1 负载（1 阀 + 1 泵）约 1A，3A 模块足够。
2. **MOSFET 板接线**：电源侧 VCC=12V、GND 与 Pi 的 GND **共地**；控制侧
   IN1 ← Pi GPIO5（阀）、IN7 ← GPIO20（泵），与 `adhesion.py` 里
   `VALVE_PINS[0]=5`、`PUMP_PIN=20` 对应（改接了就同步改常量）。
3. 先不接阀和泵，GPIO 点动看板上指示灯/输出端电压：
   ```bash
   sudo apt install -y python3-lgpio gpiod
   pip install lgpio smbus2        # 即 pyproject 的 [pi] 附加依赖
   python - <<'EOF'
   import lgpio, time
   h = lgpio.gpiochip_open(0)      # 报错就试 4；gpioinfo | grep pinctrl-rp1 确认编号
   for pin in (5, 20):
       lgpio.gpio_claim_output(h, pin, 0)
       lgpio.gpio_write(h, pin, 1); time.sleep(1); lgpio.gpio_write(h, pin, 0)
   lgpio.gpiochip_close(h)
   EOF
   ```
4. 通过后接上阀和泵再点动一遍：阀咔哒、泵转。

## 第 5 步 · 压力传感链路（半天）

XGZP6847A 输出 0.5~4.5V，超过 Pi 的 3.3V 体系，**必须分压**后进 ADS1115：

| 连接 | 说明 |
|---|---|
| XGZP 5V / GND | 接 Pi 引脚 2(5V) / 6(GND) |
| XGZP Vout → 10k → A0，A0 → 10k → GND | 1:1 分压，4.5V→2.25V |
| ADS1115 VDD/GND | 接 Pi 3.3V / GND（**VDD 接 3.3V，不是 5V**） |
| ADS1115 SDA/SCL | Pi 引脚 3 / 5（I2C1） |
| ADS1115 ADDR → GND | 地址 0x48 |

1. `i2cdetect -y 1` 应看到 `48`。
2. 读电压：
   ```python
   from smbus2 import SMBus
   import time
   def read_a0_v(addr=0x48):
       with SMBus(1) as bus:
           bus.write_i2c_block_data(addr, 0x01, [0xC3, 0x83])  # A0 单端 ±4.096V 单次
           time.sleep(0.01)
           hi, lo = bus.read_i2c_block_data(addr, 0x00, 2)
           raw = (hi << 8) | lo
           return (raw - 65536 if raw > 32767 else raw) * 4.096 / 32768
   print(read_a0_v() * 2)   # ×2 = 分压前的传感器电压
   ```
3. **两点定标**：
   - 大气下记录传感器电压 `V_ATM`（0~-100kPa 版应接近 4.5V）；
   - 用手（或下一步装好的泵）抽到泵极限，电压应单调走向另一端，
     按 (V_ATM, 0kPa) 和 (极限电压, 泵标称 -75kPa 附近) 两点确认斜率符号，
     满量程斜率标称 100kPa/4V = 25：`kPa = 25 × (V − V_ATM)`（抽气电压下降的批次），
     方向反了斜率取负。真空度必须换算出**负值**。
   - 把 `V_ATM` 和斜率记下来，第 7 步回填。

## 第 6 步 · 组装真空回路 + 手动验证（不经软件，半天）

P1 单足回路（`CLIMBING-DESIGN.md` §4 气路图的单足子集）：

```
泵(抽气口) ← 单向阀 ← 储气罐(PET瓶) ← 三通阀[P口] ；三通阀[A口] → 三通 ┬→ 吸盘
                                        三通阀[R口] = 大气              └→ XGZP6847A
```

1. **储气罐**：碳酸饮料 PET 瓶（耐负压，普通矿泉水瓶会吸瘪）。瓶盖钻两孔插
   4mm 管，热熔胶+环氧双重密封。
2. **单向阀方向**：箭头（气流方向）指向泵——即允许"罐→泵"抽气、阻止大气倒灌。
   装好后停泵，罐压不回升即装对。
3. **传感器位置**：P1 只有 1 个 XGZP，用三通接在**阀-吸盘之间**（吸盘支路的压力
   才是验收对象）。想同时监控罐压就再买一个（¥20，BOM 表 2 本来就写 3~6 个）。
4. 接头全部：插到底 + 扎带锁紧；宝塔接头处可加一圈生料带。
5. **手动验证**（跳过软件，隔离问题）：直接给泵 12V，吸盘按在擦净的玻璃上，
   看第 5 步的电压读数——应能到 -60kPa 以下。到不了就肥皂水抹接头找漏，
   或逐段夹管二分法定位。

## 第 7 步 · 实现 Pi5VacuumIO 并联调（1~2 天）

把 `software/hexapod/adhesion.py` 里的 `Pi5VacuumIO` 占位类替换为实现
（常量按第 3/5 步实测回填）：

```python
class Pi5VacuumIO:
    """树莓派 5 实机 IO。P1 台架:1 阀 1 泵 1 传感器;P4 扩到 6 阀 2 泵。"""
    VALVE_PINS = [5]
    PUMP_PIN = 20
    VALVE_ON_LEVEL = 1     # set_valve(True)=吸盘接通真空 的 GPIO 电平,按第 3 步实测
    ADS_ADDR = 0x48
    V_DIV = 2.0            # 1:1 电阻分压
    V_ATM = 4.50           # 第 5 步实测大气点电压
    KPA_PER_V = 25.0       # 第 5 步实测斜率(含符号)
    GPIOCHIP = 0           # 打不开就改 4

    def __init__(self, n_feet=1):
        import lgpio
        from smbus2 import SMBus
        self._lg, self.n = lgpio, n_feet
        self._h = lgpio.gpiochip_open(self.GPIOCHIP)
        for p in self.VALVE_PINS[:n_feet]:
            lgpio.gpio_claim_output(self._h, p, 1 - self.VALVE_ON_LEVEL)
        lgpio.gpio_claim_output(self._h, self.PUMP_PIN, 0)
        self._bus = SMBus(1)

    def set_valve(self, i, on):
        self._lg.gpio_write(self._h, self.VALVE_PINS[i],
                            self.VALVE_ON_LEVEL if on else 1 - self.VALVE_ON_LEVEL)

    def set_pump(self, on):
        self._lg.gpio_write(self._h, self.PUMP_PIN, 1 if on else 0)

    def _read_v(self, ch=0):
        import time
        self._bus.write_i2c_block_data(self.ADS_ADDR, 0x01, [0xC3 + (ch << 4), 0x83])
        time.sleep(0.01)
        hi, lo = self._bus.read_i2c_block_data(self.ADS_ADDR, 0x00, 2)
        raw = (hi << 8) | lo
        return (raw - 65536 if raw > 32767 else raw) * 4.096 / 32768

    def read_foot_kpa(self, i):
        return self.KPA_PER_V * (self._read_v(0) * self.V_DIV - self.V_ATM)

    def read_tank_kpa(self):
        # P1 单传感器在吸盘支路,罐压暂用同一读数近似——泵的滞环控制因此不准,
        # 台架测试期间泵手动控制或常开即可;P4 罐上加独立传感器后恢复滞环。
        return self.read_foot_kpa(0)

    def close(self):
        self._bus.close()
        self._lg.gpiochip_close(self._h)
```

改完先跑 `pytest tests/`（Mock 路径必须不受影响），再上台架跑完整状态机循环：

```python
import time
from hexapod.adhesion import AdhesionController, FootState, Pi5VacuumIO
io = Pi5VacuumIO(n_feet=1); ctl = AdhesionController(io, n_feet=1)
io.set_pump(True); time.sleep(3)            # 先把罐抽起来（泵手动控制）
t0 = time.time(); ctl.request_attach(0)     # 吸盘此时应已压在玻璃上
while not ctl.is_attached(0):
    ctl.update(0.02); time.sleep(0.02)
    if ctl.state[0] is FootState.FAULT:
        raise SystemExit("SUCKING 超时——没吸住,查密封")
ta = time.time() - t0
print(f"吸附确认 {ta:.2f}s  压力 {io.read_foot_kpa(0):.1f} kPa")
time.sleep(3)
t1 = time.time(); ctl.request_release(0)
while ctl.state[0] is not FootState.RELEASED:
    ctl.update(0.02); time.sleep(0.02)
tr = time.time() - t1
print(f"释放 {tr:.2f}s  循环合计 {ta+tr:.2f}s (验收目标 <2s)")
io.set_pump(False); io.close()
```

## 第 8 步 · 三条数据曲线（竖直玻璃，1 天）

玻璃/瓷砖先酒精擦净。压力记录脚本（20Hz 存 CSV，测完 scp 回开发机看）：

```python
import time, csv, sys
from hexapod.adhesion import Pi5VacuumIO
io = Pi5VacuumIO(n_feet=1)
with open(sys.argv[1], "w", newline="") as f:
    w = csv.writer(f); w.writerow(["t", "kpa"]); t0 = time.time()
    while time.time() - t0 < 90:
        w.writerow([round(time.time()-t0, 3), round(io.read_foot_kpa(0), 2)])
        time.sleep(0.05)
```

| 曲线 | 操作 | 目标 | 实测 |
|---|---|---|---|
| 1 抽气时间 | 吸盘贴壁 → 开阀，计时到 -40kPa | <1s | ___ |
| 2 泄漏率 | 到 -40kPa 后停泵、阀置"保持"态，看回升 | 60s 内不高于 -20kPa | ___ |
| 3 释放时间 | 阀切放气 → 吸盘可无阻力拿开 | <0.5s | ___ |

不达标排查：曲线 1 慢 → 双头泵并联/管路缩短/罐先抽到位；曲线 2 差 → 肥皂水找漏、
吸盘唇口和玻璃重新擦、接头补胶；曲线 3 慢 → 排气口是否被堵、管径。

## 第 9 步 · 挂重、斜角、打印件复测（1~2 天，P2 的决策数据）

**安全**：配重正下方不站人不放脚，地面垫软物；配重用水瓶/砝码逐级加；建议护目镜
（吸盘崩脱会弹）。

1. **法向拉脱**：玻璃水平架起，吸盘吸在下表面，向下逐级挂重到脱落。
   理论参照 ~35N（3.5kg）@-50kPa。记录：___ kg @ ___ kPa
2. **剪切拉脱**：玻璃竖直，吸盘吸上去侧向挂重到脱落。理论约法向 5 折。
   记录：___ kg @ ___ kPa
3. **斜角容差**（决定爬墙步幅，`CLIMBING-DESIGN.md` §6 的关键输入）：
   垫 5°/10°/15°/20° 楔块（打印或木楔），每个角度做 10 次吸附：

   | 倾角 | 密封成功次数/10 | 拉脱力 |
   |---|---|---|
   | 5° / 10° / 15° / 20° | | |

   结论回填 §6：容差 ≥15° → 步幅可用 40mm；只有 10° → 收紧到 ~25mm。
4. **suction_foot 打印件复测**：吸盘金具穿过打印件底盘锁 M5 螺母（侧窗拧），
   弯头宝塔从侧窗出管，整足装到 tibia 方轴上（顶丝锁紧），重复曲线 2 和挂重。
   打印件层间漏气 → 螺母腔和底盘内面刷薄环氧/侧窗封胶；强度不够 → 加壁重打。
5. **称重**：整足（打印件+吸盘+金具+顶丝）记入 `docs/weight-log.md`。

## P1 验收核对表

- [ ] L1 腿 ±45° 标定填入 `config.py`，`pytest` 全绿，实测复核 <2°
- [x] 电磁阀断电/通电行为实测记录在案；若"断电≠保持真空"已记入 CLIMBING-DESIGN 待办
- [x] `Pi5VacuumIO` 实装（GPIO 极性、压力换算经两点定标）
- [x] 曲线 1/2/3 达标：<1s 到 -40kPa；60s 不回升过 -20kPa；释放 <0.5s
- [x] 法向/剪切拉脱力、斜角容差数据齐全，步幅结论回填 §6
- [x] **竖直玻璃挂 1.5kg (30mm吸盘极限) 保持 10 分钟**（用 suction_foot 打印件整足做）
- [x] **"吸-确认-放"循环 <2s**（状态机跑通，非手动）
- [x] 整足重量记入 weight-log
- [ ] P2 备料下单：L 形支架材料、导轨/抽屉滑轨+滑车、1.5kg 配重、竖直玻璃板

全部勾选 → 进入 P2（单腿爬墙决策门）。P1/P2 期间打印机空闲，可开始打整机结构件。

## 常见问题

| 症状 | 处理 |
|---|---|
| `i2cdetect` 看不到 0x48 | SDA/SCL 接反；ADDR 悬空（默认 0x48 但要接 GND 确认）；I2C 没开（P0 已开过，`raspi-config` 复查） |
| 压力读数恒定不变 | 分压电阻没接/接错通道 A0；传感器 5V 供电没接 |
| 状态机永远到不了 ATTACHED | 换算符号错了——真空度必须是负值，检查 `KPA_PER_V` 符号 |
| 阀不动作 | 12V 实测（XL6009 带载跌压）；MOSFET 触发电平与共地；线圈电阻是否开路 |
| 泵转但抽不动 | 双头泵接错口（抽气口 vs 排气口）；单向阀装反；管路某接头大漏 |
| PET 瓶吸瘪 | 换碳酸饮料瓶；或罐目标真空降到 -60kPa |
| `lgpio.gpiochip_open` 报错 | Pi 5 芯片编号 0/4 随内核版本，`gpioinfo` 确认；用户加入 `gpio` 组或 sudo |
| 泵一直不停 | P1 单传感器下 `read_tank_kpa` 是近似值，滞环失准属预期，台架期泵手动控制 |
| 断电后吸盘马上掉 | 第 3 步的阀型问题（断电通大气），不是漏气；见该步处理 |
| 吸盘在玻璃上打滑 | 唇口或玻璃有灰/油，酒精擦两者；真空度不足 -40kPa |

## 安全

- 12V 回路先断电再改线；XL6009 输出端短路会瞬间烧管。
- 阀/泵是感性负载，确认 MOSFET 板带续流二极管（光耦板一般有，裸管板要自己加）。
- 挂重测试：人不在配重下方，逐级加重，玻璃边缘贴胶带防崩边。
- 泵连续堵转运行会发热，单次测试 ≤5 分钟，摸着烫就歇。
- 锂电池规矩同 P0：充电不离人、XT60 快断随手可拔。

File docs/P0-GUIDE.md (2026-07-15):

# P0 准备阶段 · 详细操作指南

目标（1~2 周）：**第一批器件到货，Pi 5 软件环境全绿，一条腿装配完成并能由 Pi 控制摆动。**
本阶段结束时你应该能拍出一段视频：SSH 进 Pi 敲命令，桌上的一条蜘蛛腿抬起又放下。

各步骤可并行：第 1 步（下单）当天做完，等快递期间做第 2 步（Pi 环境）和第 3 步（打印）。

---

## 第 1 步 · 下单第一批器件（第 1 天）

按 `BOM.md` 表 1/表 2 的规格执行，本批清单与下单前必须和卖家确认的点：

| # | 器件 | 数量 | 下单前确认 |
|---|---|---|---|
| 1 | 35kg·cm 数字舵机（DS3235/ZOSKAY 级） | 4 | ①**180° 控制角**版本（不是 270°）②工作电压含 7.4V ③带舵盘和螺丝 |
| 2 | Pimoroni Servo2040 | 1 | 正品（代购/海淘，周期最长，最先下单） |
| 3 | 5V/5A DC-DC 降压模块 | 1 | 输入范围含 6~8.4V；带 USB-C 口的更方便直连 Pi |
| 4 | 2S 锂电 5000mAh+ XT60 + B3 充电器 | 各1 | 电池带保护板或自备低压报警器 |
| 5 | 555 双头真空泵 12V | 1 | 极限真空 ≤-75kPa |
| 6 | 二位三通电磁阀 12V | 2 | **常闭型**（断电=气路断开保持真空）——必须文字确认 |
| 7 | 30mm 2.5折波纹真空吸盘 | 3 | 配 **M5 通孔金具 + 90° 弯头宝塔**（气从螺柱中心走） |
| 8 | XGZP6847A 压力传感器 0~-100kPa | 1 | 模拟输出版（不是 I2C 版） |
| 9 | ADS1115 模块 | 1 | — |
| 10 | 8 路 MOSFET 驱动板 | 1 | 光耦隔离版更好 |
| 11 | XL6009 升压模块 | 1 | — |
| 12 | 4×6mm 硅胶管 5m + 4mm 三通/直通/单向阀 | 1套 | — |
| 13 | M1.6×6 内六角螺丝 100 装、M2.5×6、M3 | 各1包 | M1.6 是舵盘-打印件连接的主力 |
| 14 | 杜邦线、XT60 对插、16AWG 硅胶线、热缩管 | 若干 | — |

预算合计约 ¥600~950。第二批（15 个舵机等）**此时不买**。

## 第 2 步 · Pi 5 软件环境（第 1~3 天，无需任何硬件）

1. **烧录系统**：官网 Raspberry Pi Imager → 选 **Raspberry Pi OS Lite (64-bit)** →
   点齿轮预配置：主机名 `spider`、开 SSH、填 WiFi、用户名密码。
2. **首次登录与基础配置**：
   ```bash
   ssh <用户名>@spider.local
   sudo apt update && sudo apt install -y git python3-venv i2c-tools
   sudo raspi-config nonint do_i2c 0        # 开 I2C（ADS1115 用）
   sudo usermod -aG dialout $USER            # 串口权限（Servo2040 用）
   # 重新登录使组权限生效
   ```
3. **部署本仓库**：把开发机上的仓库推到你的 git 远端后在 Pi 上 clone，
   或直接 `rsync -a --exclude .venv --exclude .git ~/spider/ <用户名>@spider.local:~/spider/`。
4. **安装并验证软件包**：
   ```bash
   cd ~/spider/software
   python3 -m venv .venv && source .venv/bin/activate
   pip install -e ".[sim,dev]"
   pytest tests/                             # 期望：18 passed
   python scripts/sim_walk.py --gif /tmp/walk.gif --seconds 2
   python scripts/stand_up.py --mock         # 干跑，Ctrl-C 退出
   ```
   把 `/tmp/walk.gif` scp 回来看一眼：六足三角步态动画即为通过。
5. **供电检查习惯**（以后每次都做）：`vcgencmd get_throttled` 输出必须是 `0x0`，
   非零说明欠压/降频，先解决供电再继续。

## 第 3 步 · 3D 打印（第 1~4 天，与快递并行）

打印一条**左前腿 L1**（选左前是因为软件默认配置的测试通道就是它：15/16/17）：

| 文件（`hardware/makeyourpet-hexapod/STL/`） | 数量 | 说明 |
|---|---|---|
| `left-coxa2.stl` | 1 | 同名多版本取编号最大（coxa2 > coxa） |
| `left-femur.stl` | 1 | — |
| `hardware/climbing-parts/left-tibia-suction.stl` | 1 | 吸盘足一体化小腿（替代 left-tibia.stl，末端腔体直接卡吸盘） |
| `tip.stl` | 1 | 普通足尖（P0 摆动测试用，可套在旧 left-tibia 上） |
| `calibration-arm.stl` + `calibration-ruler.stl` | 各1 | 官方舵机标定工具，P1 标定 ±45° 脉宽要用 |
| `hardware/climbing-parts/suction-foot-door.stl` | 1 | 吸盘腔门盖（吸盘放入后 502 粘死） |

参数：coxa/femur 用 PLA、4 壁、40% 填充、0.2mm 层高；`left-tibia-suction.stl`
建议 PETG、5~6 壁、45% 填充，**立打**（吸盘腔朝下）+ brim ≥8mm，tibia 细节可开支撑；
`suction-foot-door.stl` 外平面朝下、无支撑。腿部件的摆放方向和是否加支撑，跟着官方
视频走（YouTube 频道 **MakeYourPet**，装腿是第 1 集）；装配小件（limiter、
servo-back-hole2 等）按视频里单腿所需补打。
打完先干配一次：吸盘连金具从正面推入腔体，凸筋应"咔"进 Ø15 凹槽、两颗螺母落进
六角袋不能转动，盖上门无明显旷量；过紧/过松改 `tools/generate_climbing_parts.py`
的 `gap_d`/`gap_hex`（±0.2mm）重打。确认无误后再上 502 粘门。

## 第 4 步 · Servo2040 刷固件（到货当天，5 分钟）

1. 下载社区固件：
   https://github.com/EddieCarrera/chica-servo2040-simpleDriver/releases/download/v0.0.1/chica-servo2040_release.uf2
2. **按住板上 BOOT 键**插 USB → 电脑出现 `RPI-RP2` U 盘 → 把 .uf2 拖进去 → 自动重启完成。
3. 验证：插到 Pi 上，`ls /dev/ttyACM*` 应出现设备；然后：
   ```bash
   cd ~/spider/software && source .venv/bin/activate
   python -c "from hexapod.driver import Servo2040Driver; d=Servo2040Driver(); print('电压', d.read_voltage_v()); d.close()"
   ```
   此时未接舵机电源，读数取决于板子背面 "Separate USB & Ext. Power" 跳线：
   未割断（出厂默认）读数约 5V（读到的是 USB 的 5V 供电轨）；已割断则接近 0。
   两种情况下能打印出数字，就说明 USB 通信链路通了。
   ⚠️ 第 5 步接 2S 电池**之前必须先割断该跳线**（接线图上标注 "CUT THIS!"），
   否则电池的 7.4~8.4V 会经 USB 线倒灌进 Pi，可能烧毁 Pi。

## 第 5 步 · 单腿装配（舵机到货后，半天）

⚠️ 顺序很重要：**先让舵机回中，再装舵盘，最后装结构件**，装反了标定全错。

1. **接电池前的强制检查**（三项全部通过才允许接电池，任何电源都没接时先做第一项）：
   - [ ] **割断**板背面 "Separate USB & Ext. Power" 跳线（接线图上标注 "CUT THIS!"）。
         不割就接 2S 电池，电池电压会经 USB 线倒灌烧毁 Servo2040 和 Pi 的 USB 口。
   - [ ] **验证割断**：只插 USB、不接电池，跑第 4 步的读电压命令——
         读数**接近 0** 才算割断成功；仍读到约 5V 说明没割透，回去补割再测。
   - [ ] **万用表实测**电池引出线/XT60 的正负极后再接 EXT 端子，**不要只看线色**
         （自购引出线偶有红黑接反，反接瞬间烧板）。

   养成习惯：接/拔电池前先拔 USB，两路电源永远不同时插拔。
2. **接线**（对照 `hardware/makeyourpet-hexapod/wiring-diagram-servo2040.png`）：
   3 个舵机信号线接 Servo2040 通道 **15(coxa) / 16(femur) / 17(tibia)**；
   舵机电源按官方接线图接 2S 电池（P0 可暂不装继电器，直连，但要装 XT60 快断）。
3. **回中**：
   ```bash
   python scripts/servo_center.py            # 全部通道回中 1500µs 并使能
   ```
   听到舵机锁定即成功。此时**不要**用手掰舵机。
4. **装舵盘**：按官方视频的中位角度把舵盘压上花键、上锁紧螺丝——
   coxa/femur/tibia 的中位姿态分别对应官方安装偏角 -8°/35°/68°（视频里有对齐示意）。
5. **装结构件**：coxa → femur → tibia 依次装配（视频第 1 集），M1.6 螺丝连接舵盘与打印件。

## 第 6 步 · 摆动测试与验收（1 小时）

```bash
python scripts/servo_center.py                       # 回中基准
python - <<'EOF'                                     # 三关节各扫一遍 ±20°
import time
from hexapod.driver import Servo2040Driver
d = Servo2040Driver()
d.set_all_pulses_us([1500]*18); d.enable(True); time.sleep(1)
for ch in (15, 16, 17):
    for us in (1280, 1720, 1500):
        d.set_pulses_us(ch, [us]); time.sleep(0.8)
d.close()
EOF
```

**P0 验收核对表**：

- [ ] 第一批器件全部到货，常闭阀/180°舵机/M5通孔金具经实物核对
- [ ] Pi：`pytest` 18 项全过、`sim_walk.py` 出 GIF、`get_throttled` = 0x0
- [ ] Servo2040 刷好固件，Pi 能读电压
- [ ] 电源跳线已割断（只插 USB 读电压接近 0），电池极性经万用表确认
- [ ] 单腿三关节按指令平滑摆动，无抖动、无异响、结构无松动
- [ ] 吸盘+金具推入 `left-tibia-suction.stl` 腔体到位，螺母入六角袋不转动，门盖干配无旷量
- [ ] 整腿称重记录（写进 `docs/weight-log.md`，预算参考：单腿含舵机 ~230g）

全部勾选 → 进入 P1（吸附台架验证）。

## 常见问题

| 症状 | 处理 |
|---|---|
| `/dev/ttyACM0` 不存在 | 换数据线（很多 USB-C 线是纯充电线）；确认固件刷成功（板上 LED 彩虹流动=等待连接） |
| 打开串口 Permission denied | `dialout` 组没生效，重新登录；或临时 `sudo chmod 666 /dev/ttyACM0` |
| 接电池后板子/Pi 冒烟、无响应 | 大概率跳线没割断致电池电压倒灌，或电池极性接反。立即断电池拔 USB；换一台电脑按 BOOT 测板子是否还能出 `RPI-RP2`；Pi 逐口插已知好设备验证 USB 口 |
| 舵机不动但通信正常 | 忘了 `enable(True)`（RELAY 使能）；或舵机电源没接/电池没电 |
| 舵机抖动/嗡嗡响 | 2S 电压低于 6.8V 先充电；信号线与电源线分开走；单条腿负载下抖动属异常，换备用舵机排查 |
| 回中后舵盘角度装不准 | 舵盘花键有齿距，装最接近的一格，残差以后用 `config.py` 的 `attach_deg` 修 |
| Pi 频繁重启/降频 | `get_throttled` 非 0：换 5V/5A 供电，别用电脑 USB 口带 Pi |
| 吸盘推不进腔体/螺母卡不进六角袋 | 打印件 XY 公差偏紧：`gap_d`/`gap_hex` 加 0.2 重打，或用锉刀修；过松晃动则减 0.2 |

## 安全

- 锂电池充电不离人，用 B3/B6 平衡充；测试台上装 XT60 快断，异响立即断电。
- 35kg 舵机堵转扭矩很大：通电状态手指不要放进关节转动范围。

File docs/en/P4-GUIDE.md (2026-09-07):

> English translation of [`docs/P4-GUIDE.md`](../P4-GUIDE.md). The Chinese original is the maintained source; if they differ, the Chinese version wins.

# P4 whole-robot wall-climbing integration · detailed operating guide

Goal (weeks 15–26): **6 suction feet + the complete pneumatic system on the robot, the gait coupled to the adhesion state machine,
climbing a vertical glass/tile wall.**
Acceptance (ROADMAP): climb 1m up, translate 0.5m sideways, hang in place for 5 minutes with the power off without coming loose; safety line throughout.
The ground-to-wall transition is **not** part of this stage: the robot is put on the wall by hand (the transition move is P5).

Two tracks run in parallel in this stage: the **hardware track** (pneumatic bay assembly + pneumatics + electrical, gated by printing and deliveries) and
the **software track** (gait engine rework + adhesion integration, which can start any time on MockVacuumIO/MockDriver).
The software track is the real bulk of the work in this stage; start there.

Prerequisite check:

- [ ] Every box of the P3 acceptance checklist ticked (2m straight / 360° turn / 2cm obstacle / FK <5mm / print inventory)
- [ ] All 18 ±45° calibrations in `config.py` (2026-08-08 ✅, including whole-robot standing verified on the real robot)
- [ ] Whole robot (no adhesion) weighed into `weight-log.md` — **this one is still blank, do it first**; start weight reduction above 2.2kg
- [ ] P4 pneumatic bay V1 has passed its standalone validation (`validate_p4_bay_v1.py` 22/22, see P4-BAY-DESIGN §6)
- [ ] Vacuum tank has arrived (the V1 tank clamp waits on the real ear spacing, see P4-BAY-DESIGN §4-11)
- [ ] Pi environment healthy: `pytest` all green, `get_throttled` = 0x0

---

## Step 0 · Three things to settle first (they shape every job that follows)

**1. The gait engine needs a structural rework, not parameter tuning.** P3's `gait.py` is a pure open-loop phase table:
it assumes the ground is always at z0 and that touchdown happens exactly on a phase boundary; vertical speed happens to be at its maximum
at the instant of touchdown (≈170mm/s with default parameters, "slapping the ground"); the moment the phase boundary passes, the foot is dragged sideways. All three are the
opposite of what "land and seal" needs. P4 must make it **event-driven**: phase advance can be paused by each leg's
adhesion events, and the end of the swing phase becomes "decelerating vertical descent → press in → wait for vacuum confirmation".
See step 4 for details.

**2. The adhesion math must be redone with the measured weight.** P4-BAY-DESIGN §2.4 already threw cold water on this: the adhesion system's
implicit budget is 0.6kg, the rough estimate is 0.94–1.11kg, and the whole robot is estimated to land at 2.6–2.8kg. Measured on a single cup on vertical
glass: 25N normal pull-off, 15N shear (CLIMBING-DESIGN §omissions). Five feet in stance carry 75N of shear,
a safety factor of ≈2.7 against 2.8kg (28N) — still alive, but every part must be weighed into
`weight-log.md` as it arrives, and before going on the wall this math must be redone with the measured whole-robot weight and written into the acceptance table of this file.
**Filled back in 09-04**: the whole robot (with adhesion) measured 3537g = 34.7N; 75N of shear on five feet → safety factor **2.16**, 60N on four feet with one lost → **1.73**. The real robot has done every wall test at this weight; see `weight-log.md` for the conclusions.

**3. Three principles of servo protection** (the conclusion of the P3 servo discussion, running through all of the gait design):

| Principle | How it is applied |
|---|---|
| Transient external force is acceptable | Occasional tugs from adhesion, retries after a press that wasn't deep enough — no need to chase zero external force |
| **Steady-state fighting must be removed by changing the command** | PWM servos have no per-channel enable, no torque mode, no position readback; the only lever is to make the command follow the physics (preload travel, section 4.2); criterion = total current falls back to baseline after attachment |
| Never exceed stall | Derate 35kg·cm by 50% (the P2 measurement basis); a slow gait beats a fast one; never force a joint by hand while enabled |

The essential difference between the wall and the floor: on the wall a stance foot carries shear load **continuously** (P2 measured 0.61A for a single leg in
hold), so five feet in stance means ~3A of continuous current plus continuous heating. This is normal, not a fault —
the `walk_teleop`-style voltage/current status line must be kept, with peak and per-foot fall-back criteria added.

## Step 1 · Hardware track: first article and assembly of the pneumatic bay (1–2 weeks, in parallel with the software track)

Execute in the order of P4-BAY-DESIGN §5.4 / §6.3; only the check items are listed here:

- [ ] `p4-bay-fit-template-v0` on the robot, all six legs swung slowly through full travel with no interference (dynamic sweep, not optional)
- [ ] Test-fit the pump adapter plate / valve rail / sensor bridge / manifold clip one by one with real parts: assembles by hand, no wobble, not forced together by screws
- [ ] Re-check three things: the fore-aft offset of the 555 pump body relative to the bracket holes, how far the 0520B plastic nozzle actually protrudes, printed hole tolerance
- [ ] Vacuum tank arrives: first pull **-70kPa as a crush test** on the tank alone, then generate the tank clamp from the measured ear spacing
- [ ] Pre-fit all PCBs on the electrical deck with no power applied; check terminals / wire bends / vibration swing (V1 left 10 service zones)
- [ ] Weigh the assembled bay into `weight-log.md`; **single pump for the first flight** (-130g), the second pump position left open
- [ ] Battery stays in the official position on the belly (the belly faces the wall while climbing = CG closest to the wall, P4-BAY-DESIGN §0-1)

Connection topology per `html/en/p4-system-diagram.html` / `html/en/p4-pneumatic-electrical.html`;
build the divider board per `html/en/p4-divider-board.html`; wire the Pi per `html/en/p4-pi-wiring.html`.

Wiring discipline (carried over from P3, all mandatory): comb 12V power wires apart from analog sensor wires; no breadboards or
Dupont jumpers anywhere in the bay (intermittent disconnects under vibration = state machine misjudgment = fall); sensor wires run on an IDC ribbon that clips onto the Pi 40-pin header as one piece.

## Step 2 · Electrical and IO: `Pi5VacuumIO` from 1 foot to 6 (2–3 days)

> **2026-08-14, software side done**: items 1–6 below are all coded into `adhesion.py` (the GPIO table was
> jogged and measured on 08-14; the 7-sensor mapping follows p4_sensor_check; glitch suppression changed to a time-window
> criterion; tank pressure on its own channel + out-of-range judged as sensor failure, which stops the pump and sets `tank_fault`; arbitration field `mode` is a placeholder).
> Still to verify on the real robot: the timing of the whole chain in the 50Hz main loop (the ADS has already been raised to 860SPS + a 0.05s reading cache).

Today's `adhesion.py` is the P1 test-rig version: `VALVE_PINS = [5]`, one pump, one ADS1115. P4 extends it:

1. **Channel allocation**: the YYNMOS-8 has exactly 8 channels = 6 valves + 2 pumps (both pump channels are defined for the first flight, only 1 is wired).
   Freeze the GPIO pin table and write it into the `Pi5VacuumIO` class constants, matching the leg order in `config.py` one for one.
2. **7 pressure channels**: 2 × ADS1115 (0x48/0x49) give 8 channels, 6 foot pressures + 1 tank pressure.
   Mount the foot pressure sensor **between the valve and the cup (cup side)** — foot pressure can then be read even with the valve closed, and adhesion confirmation and
   hiccup detection both depend on it (the single-sensor lesson from P1 + the P2 hiccup measurement where 30s goes out of control).
   PGA must be ±4.096V (±2.048 clips in the vent-confirmation band, see the comments in `adhesion.py`).
3. **Per-channel electrical verification** (pneumatics not connected): the tool is `scripts/p4_sensor_check.py`; it only reads I2C
   and never touches GPIO, so it runs even before the pneumatics and the MOSFET board are installed. With no arguments it prints a self-test report (a verdict for each of the 8
   channels + consistency of the atmospheric point + noise), `--live` verifies the read chain while sucking, and `--wiggle N`
   catches intermittent breaks (see the next item). Test the valve side separately: every valve is audible when it pulls in, the pump starts and stops.

   **2026-08-11 measurement (six foot-pressure channels; tank and spare not connected)**: spread of the atmospheric point 12mV ≈ 0.3kPa,
   noise 1.0mV ≈ 0.05kPa. The deviation is far below the -30kPa criterion, so **one common `V_ATM=4.486` is enough,
   there is no need to calibrate each sensor** (the planned "table of 7" can be dropped; if you really want to calibrate, use `--zero --save`).

   The direction of the range follows the P1 measurement: **atmosphere 4.5V, -100kPa 0.5V, so after the divider the atmospheric point reads ADC ≈2.243V**.
   The line "atmosphere ≈0.25V" in the inspection checklist of `html/en/p4-divider-board.html` is backwards; checking against it will
   make you condemn a good board. An unconnected channel is pulled to ground ≈0V by the lower 10k arm, which is how you tell it from a live channel;
   the 8th channel has pads only with no divider fitted, so a floating AIN with a drifting reading is normal.

4. **Glitch suppression (new, mandatory)**: the state machine currently uses a single-sample criterion — one reading of
   `read_foot_kpa(i) <= ATTACH_KPA` in `adhesion.py` flips it to ATTACHED. **Change it to N consecutive
   samples all satisfying the criterion, or take a median filter**; the ATTACHED leak alarm (pressure recovering by >10kPa) gets the same treatment.

   The reason: foot pressure is the only basis for judging ATTACHED, and one false deep-vacuum reading makes the state machine believe that foot
   is stuck, so it clears the next leg to lift and five feet in stance become four. The criterion has to survive a single-sample glitch.

   **A misdiagnosis on 2026-08-11; the procedure is written down for reuse.** Symptom: S7's reading jumped whenever it was touched,
   then stopped jumping later; `--wiggle 7` caught 100 "intermittent breaks". I nearly went and unsoldered the joints; the real conclusion was
   **coupling from human static electricity, the board was perfectly fine**. A three-step elimination:

   | Step | Observation | Conclusion |
   |---|---|---|
   | `--wiggle`, look at direction | Strictly alternating positive and negative, symmetric amplitude | A real intermittent break is **one-directional** (with the wire broken, the divider node is only pulled toward ground by the lower arm); alternating = swinging around the baseline, not a disconnect |
   | `--scope`, look at amplitude | Maximum excursion only -2.8kPa | A real open circuit should slam to **-112kPa** (full scale). A wire is either broken or not; it does not break "a little bit" |
   | Separate "electrical" from "mechanical" | Pressing with a plastic pen barrel (force only) does nothing; a light touch after discharging static (charge only) reproduces it | Charge injection, not mechanical/piezoelectric |

   The decisive step was **comparing against another channel**: `--scope 2` behaved exactly the same → a board-level trait,
   nothing to do with S7's soldering. **Whenever you suspect one channel, measure a second one as a control first**; it saves a lot of rework.

   In flight the robot runs on battery and nobody touches it, so the human-static path does not exist and this phenomenon is no threat on the wall.
   But it proved one real thing: **the divider node really is sensitive to injected charge** — source impedance 10k∥10k = 5k,
   the 100nF corner frequency is 318Hz, which only blocks high frequencies. The real attackers in flight are **pump/valve switching transients and
   servo current surges**, which live in the same low band, so this must be re-measured after the pump and valves are installed in step 3 (see below).

   Tool usage: `--wiggle N` catches intermittent breaks (it automatically recognizes alternating signs and suggests switching to `--scope`),
   `--scope N` produces a waveform plot + spectrum; judge it by "direction + amplitude" — only fully one-directional with >20kPa peak-to-peak
   is a real intermittent break, and only then do you localize it in the seven steps "sensor body → wire exit at the root → middle of the harness → S-port connector →
   tap the solder joints → flex the board"; the fix is re-crimping the terminal or soldering directly with heat-shrink, **not "plug it in again"**.
   Software glitch suppression is the second line of defense; it cannot replace the first.

5. **The tank pressure channel trap**: `read_tank_kpa()` currently just returns `read_foot_kpa(0)`. With the vacuum tank
   not yet delivered and S1 empty, that channel reads ≈0V, which converts to **-112kPa**, lower even than `PUMP_OFF_KPA=-65`
   → the pump hysteresis thinks the tank has plenty of vacuum → **the pump never starts**. Fix this while extending to 7 channels:
   give tank pressure its own channel number, and raise a sensor-failure alarm when a reading falls outside the sensible -100 to +10kPa range.
6. **Arbitration field** (reserved for the far-future dual-surface hybrid foot): leave a `mode` field per foot as a placeholder in the gait-layer interface of
   `AdhesionController`; in this stage it is always `suction` and implements no logic.
7. The high-side relay for the servo main power (breaking the positive) was **settled on 08-15 to be driven by Pi GPIO17 (Pin11)**,
   no longer by Servo2040 A0/GPIO26: the module's jumper goes to **H** (pull in on a high level), the coil DC+
   takes the 5V/5A buck output (same source as the Pi, ~100mA), DC− shares ground, IN1 ← GPIO17.
   `driver.enable()` still sends the serial RELAY command (to keep the firmware enable), while the power switching is owned by GPIO17.
   The benefit: when the chica firmware locks up, the Pi can still cut servo power on its own; when the Pi process exits or reboots, the GPIO returns
   to input state → the relay releases automatically, a natural emergency-stop backstop. Cutting servo power does not affect the Pi or the pneumatics — this is
   the basis for graded emergency stop on the wall: cut the servos first (the NC valves hold the vacuum, the robot stays hanging), then a human takes over.

## Step 3 · Pneumatic assembly and leak testing (2–3 days)

The chain (one run from tail to front): pump → check valve → vacuum tank → tank-port tee (tank pressure sensor) →
manifold (1-in-6-out) → 6 × NC valve → pressure-tap tee (foot pressure sensor) → service loop over the coxa → suction cup.

- [ ] The whole chain on 4mm barbs + cable ties, epoxy at the joints (no hot glue)
- [ ] Leak-test in sections: first "pump → tank" pulled to -70kPa and held, then open each foot's valve in turn and test out to the cup (lip pressed on glass)
- [ ] Re-measure the whole-chain leak rate (the P1 basis: hold -40kPa for >60s without falling to -20kPa);
      **the upper limit of the 5-minute powered-off hang acceptance is set by this curve** — if it doesn't meet spec, fix the leaks before going further
- [ ] Leave a service loop (a slack turn) where each leg's vacuum line crosses the coxa joint; no line gets tugged with all six legs swinging through full travel
- [ ] Measure pumping time: a single foot from touching the wall to -40kPa (the P1 target is <1s); measure tank recovery time, which
      decides whether the second pump goes on (criterion: tank pressure returns to the PUMP_OFF hysteresis band within one gait cycle)
- [ ] **Re-measure electromagnetic compatibility (mandatory once the pump and valves are installed)**: `p4_sensor_check.py --scope N --secs 5`,
      with the pump starting and stopping and the six valves switching one by one during the run; see how much the foot pressure channels are polluted. This is the test that really has to be passed
      — the low-frequency sensitivity of the divider node measured in step 2 has exactly these switching transients as its attacker in flight.
      Criterion: the interference amplitude must be far below the -30kPa ATTACH criterion (leave an order of magnitude of margin).
      Order of treatment if it fails: ① confirm that every solenoid valve has a **flyback diode** (the inductive kick when an inductive load is switched off
      can reach hundreds of volts; the YYNMOS-8 usually has them built in, but confirm on the physical board) → ② comb the analog wires completely apart from the 12V power
      wires, adding shielding or twisted pairs if needed → ③ only then consider larger filter capacitors.

## Step 4 · Software track: reworking the gait engine (the core workload of this stage, 2–3 weeks, Mock first)

> **2026-08-14, implementation filled back in**: 4.1–4.5 of this step are all coded — `hexapod/climb.py`
> (ClimbEngine: event-driven segmented swing + phase pause + interlock + retry + leak freeze),
> `config.py` (per-leg `press_delta_mm` + the `climb_*` parameter group), `adhesion.py`
> (time-window criteria against glitches, is_leaking/leak_time, Pi5VacuumIO with seven sensors + tank-failure
> judgment, the mode arbitration field). The integration entry point is `scripts/climb_walk.py`
> (--mock/--air/--release), visualization with `sim_walk.py --gait climb`.
> Voice shell `scripts/voice_climb.py` (09-03): climb_walk runs unmodified inside a pty, and
> voice is mapped to injected keystrokes (emergency stop "停下" ("stop") → space, "往前走" ("walk forward") → w, "开始吸附/启动" ("start adhesion / start") → p,
> "单步/落地" ("single step / land") → i, "冻结" ("freeze") → f); the interlocks and the black box are unchanged; venting-class actions such as
> exiting or taking the robot down are keyboard-only (see VOICE-GUIDE §3.9).
> Items 1 and 2 of 4.6 are done (37 pytest all green + GIF eyeball check); 3 and 4 wait for the real robot.
>
> **2026-08-16, touchdown geometry fix (§4.3 implemented, found on the real robot while suspended)**: at the default stance
> reach=130, the physical cup axis at the press-in position is ~21° off the surface normal (beyond the ±15° tolerance; it looks like
> "the K→lip-center line is perpendicular"). ClimbEngine now **solves**, per leg with `cup_delta_deg=-25.2` (the L3-DISPUTE
> ruling basis), for the stance radius that makes "the cup axis at the press-in position ⊥ the surface" (≈176mm with default parameters,
> only 1.2° off at the instant of contact), and the touchdown band is clipped to a radius interval converted from a ±12° tolerance; the velocity command is
> globally limited to `climb_max_step=40` (an attached foot must not slip, so the real stance-phase displacement must be
> ≤ the stride limit — this matches the CLIMBING-DESIGN §6 prescription "reach 170, stride ≤40").

### 4.1 The swing phase changes from "one curve" to a segmented state machine

Each leg's swing phase is split into (working with the per-foot state machine in `adhesion.py`):

```
LIFT     Lift off while venting to atmosphere: the foot tip target retreats ≥15mm along the surface normal (the cup's 11–13mm
         rebound travel would push the foot back onto the surface, so it must vent while it moves)
TRANSFER Translate to above the touchdown point: keep the existing smoothstep + sinusoidal lift shape
DESCEND  Decelerating vertical descent directly above the touchdown point: XY frozen, approach speed cut to slow (tens of mm/s,
         value measured with the robot suspended) — kills today's slap where "vertical speed is maximal at touchdown"
PRESS    Press in by the preload travel press_delta (see 4.2): XY still frozen, slow;
         at the end, adhesion.request_attach(i) → PRESSING → SUCKING
WAIT     Wait for ATTACHED (-30kPa); phase advance pauses here, and failure to pull vacuum goes to FAULT:
         lift 5mm, back to DESCEND, retry; 3 consecutive failures → whole robot stops walking and alarms
LOAD     After ATTACHED: the foot tip target switches to holding the pressed-in position (4.2), the leg goes to stance
```

The stance phase and release are symmetric: move the CG away first (unloading that leg) → `request_release` → VENTING →
RELEASED → only then LIFT is allowed.

### 4.2 Preload travel and the two-state foot tip target (the key to killing steady-state fighting)

The three states measured in §4.4 (LEG-GEOMETRY-OPEN.md), converted into gait parameters:

| State | h_cup | Meaning |
|---|---|---|
| Free | 19–21mm **measured per leg** | Swing-phase geometry; the settled l3=123.7 is based on L1's 19 |
| Pressed to seal | 7.5mm | **press_delta = h_cup_free − 7.5 ≈ 11.5–13.5mm** |
| Vacuum -40 to -50kPa | 8mm | Only 0.5mm from the sealed state — **press to seal first, then pump; pumping barely moves it further** |

Implementation basis: **do not touch the settled `tibia_len=123.7`**; add a per-leg
`press_delta_mm` in `config.py`, and have the gait add that amount along the surface normal at the touchdown point as the foot tip target for the
press-in segment and the adhesion-hold segment. A two-state l3 and "target point plus delta" are mathematically equivalent, and the latter doesn't touch the settled calibration chain.
(Related part: `CUP_DELTA=-25.2` in `workspace_analysis.py` has been revised for the attached state
— L3-DISPUTE to-do g — use it to re-check the touchdown band.)

**Acceptance criterion (check it on every run on the real robot)**: within ~2s after ATTACHED and the target switch, the total current should
fall back close to the baseline of that stance configuration. If total current stays ~0.6A higher after a leg attaches, that leg's
press_delta wasn't fully consumed (re-measure that leg's h_cup) and the servo is fighting the vacuum.

### 4.3 Touchdown point and lip attitude constraints

- Lip tilt tolerance **±15°** (measured on the P1 test rig). A 3DOF leg cannot control the cup's orientation — tilt is
  determined by the geometry of the touchdown position, so this is a **touchdown selection constraint** (workspace layer), not something the gait can
  trim away step by step. Flat ground and a vertical wall satisfy it naturally near the design stance; a step length that puts the touchdown point outside the band is simply rejected.
- Pressing along the surface normal with XY frozen is a **hard gait rule** (settled in 4.1); otherwise the lip scrubs sideways and the seal fails.

### 4.4 Touchdown criterion

The plane's position is known (both floor and glass wall are flat), so the main route is **open-loop press-in + current watch**:
the DESCEND segment goes to the known plane height and then switches to PRESS, watching the total current increment throughout for two purposes —
early-contact warning (current jumps before the expected height is reached → stop) and touchdown confirmation. Total current resolution is
81mA/LSB, and a single leg's press-in increment is on the order of a hundred mA, so it is distinguishable; the threshold is calibrated by comparing suspended vs on the ground.
The foot pressure sensor is the second criterion: if pressure doesn't drop after the valve opens at the end of PRESS, the lip never sealed at all.

### 4.5 The CLIMB gait and the safety interlocks

- Use the CLIMB reserved at `gait.py:29` (5/6 duty, wave phasing, one leg at a time). In a tripod gait two groups of legs attach and release at the same time,
  which strains both the pump and the timing; don't use it for climbing.
- Interlock (stricter than the ≥4 in the `adhesion.py` comment; use the strict one for the first climb): **before lifting any foot, the other
  5 feet must all be ATTACHED**; adjacent feet never release at the same time (the CLIMBING-DESIGN §omissions constraint).
- ATTACHED leak alarm (pressure recovering by >10kPa): re-pump that foot immediately to save it; if 2s of that doesn't work →
  freeze the whole robot in its current pose + alarm (losing one of the five feet still leaves 4; the safety factor is 1.73 at the 3.54kg measured on 09-04).
- Pump hysteresis -60/-75kPa (deepened from -55/-65 on 2026-08-17: widening the band 10→15 stretches the interval between top-up pumping,
  and going deeper overall adds adhesion margin). ⚠ -75 sits right at the lower end of the 555 pump's nominal limit (-75 to -85), and with a check valve
  on every foot the cup-pressure floor = pump limit + valve cracking pressure — the measured cup pressure plateau must actually pass -75
  for this to count; if it can't, the pump never stops, and both thresholds must be moved back together to ≥5kPa on the shallow side of the plateau.
  Set the gait cycle to 3–4s at first (cycle_time is adjustable) and speed up once it runs smoothly.
- Slip compensation (`climb_sag_comp_mm` / `--sag-comp`, default 0 = off, added after the 2026-08-17 wall
  measurements): on a vertical wall the measurement is "every time a leg lifts, the whole robot gets dragged down a notch" — load is redistributed from 6 feet to 5,
  the elastic give (lateral deformation of the bellows cup + the servos' load-induced give angle) is locked in as a ratchet by the next attachment, and
  6 times per cycle can eat the whole stride = stepping in place. The compensation, during the LIFT+TRANSFER segment of each lift event
  (the swing foot is off the surface, no cup is pressing in), translates all stance feet at a constant rate by a set amount along the body frame's "downhill"
  direction (head up against the wall = -X, rotated with the integrated heading), pushing the body back up. The actual amount per event
  = min(setting, (40−half stride)/5): once the total outward swing at the tail of stance exceeds 40mm the leg leaves the IK envelope
  (capped at 4mm at full speed; at lower speed the stride shrinks and the cap loosens automatically); if the target leaves the workspace,
  climb_walk has a parachute — freeze and hover, so an anomaly doesn't blow up the control loop. Calibration basis: first mark a dot with a whiteboard marker next to a
  stance cup and walk 3 cycles to tell the loss types apart — **the mark stays put while the body sinks = elastic ratchet
  (compensable); the mark travels with the cup = interface slip (not recoverable, check cleanliness / cup pressure)**. Once the elastic type is confirmed,
  start at 2–3mm and increase step by step, watching the net displacement per cycle; take up to eighty percent of the measured sink. ⚠ Anything beyond
  the real sink drags the attached cup downhill along the surface, so err on the low side.

### 4.6 Development order (all on Mock first)

1. Run `MockVacuumIO + MockDriver` together with the new gait state machine and add pytest cases: normal cycle,
   SUCKING timeout retry, ATTACHED leak, interlock refusing a lift;
2. `sim_walk.py` produces a GIF for an eyeball check of the segmented swing trajectory (the vertical descent segment is visible);
3. Real robot, suspended: six legs walking the CLIMB gait in the air with the valves and pump really actuating (a cup in mid-air must FAULT,
   which conveniently exercises the retry and interlock paths);
4. Glass plate on the ground: go to step 5.

## Step 5 · Adhesive walking on the ground — timing integration acceptance (1 week)

Run the complete "press – pump – confirm – walk – release" gait on a horizontal glass plate (solidly supported, wiped clean). What this step validates
is **timing**, and the risk is zero (it can't fall); every box below must be ticked before going on the wall:

- [ ] 20 consecutive steps with no FAULT (or every FAULT recovered by an automatic retry)
- [ ] Total current falls back to baseline after every step's attachment (the 4.2 criterion), no leg fighting continuously
- [ ] Pumping time / tank recovery fit inside the gait cycle (if not: slow the cycle down or add the second pump)
- [ ] No "foot push-back" on the release side (the LIFT timing of retreating while venting is right)
- [ ] Walk and stop for 10 minutes with no servo hot to the touch (corroborating evidence that the fighting is gone and the load is normal)

## Step 6 · On the wall: progressive inclines → vertical (1–2 weeks)

Attitude principle: keep the body close to the wall (the closer the CG is to the wall, the smaller the peel moment on the upper cups; settled in the ROADMAP).

| Level | Surface | Pass criterion |
|---|---|---|
| 1 | 30° inclined glass | Climb 0.5m, no FAULT cascade |
| 2 | 60° inclined glass | Climb 0.5m + hold still for 1 minute |
| 3 | Vertical, starting 0.3m above the ground | Climb 0.5m |
| 4 | Vertical | **Acceptance: climb 1m, translate 0.5m sideways** |
| 5 | Vertical | **Acceptance: 5-minute powered-off hang** (servo power + pump power cut, the NC valves hold the vacuum; a person stands by to catch it) |

Safety line throughout every level (anchor at the top, climbing accessory cord left with a little slack, load-test the anchor first) and mats on the ground.
Sideways translation and climbing up use the same gait engine, only the velocity vector differs — the CLIMB gait itself has no preferred direction.

## Step 7 · Wrap-up and archiving

- [x] Whole robot (with adhesion) weighed into `weight-log.md`, with a conclusion against the 2.5kg limit — measured **3537g** on 09-04, 1037g over the limit; conclusions and open items in weight-log
- [x] Adhesion math redone with the measured weight, numbers written into this file (filled back into step 0, item 2) — safety factor 2.16 (five feet) / 1.73 (four feet), filled in
- [ ] Measured press_delta / h_cup of each leg into `config.py` with the date noted
- [ ] Measured curves for leak rate, pumping time and the powered-off hang stored in `docs/data/`
- [ ] P5 leftovers list: ground-to-wall transition, payload, dual-pump decision, enabling the dual-surface arbitration field

## Common problems

| Symptom | What to do |
|---|---|
| One leg times out in SUCKING often | Check in order: lip tilt (is the touchdown point at the edge of the working band?) → press_delta (has this leg's h_cup actually been measured?) → a leak in that channel's tubing/tee → clean the lip with alcohol |
| Total current doesn't fall back after attachment | press_delta wasn't fully consumed and the servo is fighting the vacuum; re-measure both h_cup states on that leg (cups vary 2mm between batches, don't apply L1's value to all of them) |
| Hiccup (foot pressure periodically recovers and gets pumped back down) | The old enemy from P2: a micro-leak. Clean the lip, check the seal of that foot's cup seat; a hiccup lasting more than 30s is treated as loss of control (the lesson measured in P2) |
| One foot pressure channel jumps occasionally / jumps when its wire is touched | **Don't jump straight to "bad contact"** (a near-misdiagnosis on 2026-08-11). In order: ① `--scope N` to look at the shape — a real intermittent break is a one-directional step that slams to around -112kPa; bidirectional spikes or a few kPa are not; ② measure another channel as a control, and if it jumps the same way it is a board-level trait, not this channel's problem; ③ pressing with a plastic pen barrel vs a light touch after discharging static, separating "force" from "charge". Only if it really is an intermittent break, localize it in seven steps with `--wiggle N`; the fix is re-crimping the terminal or soldering directly with heat-shrink |
| Freezes the moment the pump/valve moves, IO keeps failing (Errno 121) | The ADS1115 is knocked off the bus by 12V switching transients (measured 08-23: all three Errno 121 events fell within 0.05–0.6s after the pump/valve was energized, all self-healed in <1s, and the IO error count was 0 all session = the chip was healthy before it dropped off the bus; a steady TLM voltage proves nothing — that is the servo bus, it cannot see 12V/3.3V transients). The software already has a 0.5s tolerance + retry to ride over the glitch; if it recurs, check the hardware: ① flyback diodes on pump/valves ② supply decoupling of the ADC divider board (100nF+10µF) and the ground topology (don't share a path with the pump current) ③ keep the I2C wires away from the 12V bundle, add a twisted ground ④ a fully charged battery (the lower the boost board's input, the more violent the switching transients — the run that started at 7.72V blew up, the one at 8.03V was fine) |
| Tank pressure can't keep up with the step rate | Slow cycle_time down first, then add the second pump; a pump that never stops running = a systemic leak, go back to step 3 and leak-test |
| The foot is "stuck" to the surface and dragged during LIFT | Lifting before venting is finished (the VENT_TIME/RELEASE_KPA criterion was not waited out), or that channel's valve exhaust is blocked |
| On the ground walk_teleop lifts the legs barely at all, the cups don't leave the ground (only after the pneumatics were installed) | Not a weight problem: a de-energized valve = the tank-connected position, and the cup reaches the manifold through each foot's check valve, so pressing the body down squeezes air into the manifold and on lift-off the check valve won't let it flow back → the foot is locked by passive vacuum (about -40 to -60kPa on a 30mm cup ≈ 30–40N, more than the femur's pull at the foot tip). walk_teleop/voice_teleop `--vent auto` (default): the six valves are energized to exhaust while standing up and walking, and are de-energized 0.5s after walking stops and the robot settles (standing still shouldn't burn ≈25W in six coils); on start-up they are energized serially, so the feet don't lift for about 1s; `on` keeps them energized; `off` doesn't touch the valves, as a control (the v key cycles between them); any similar ground script that doesn't run the adhesion state machine but still lifts legs falls into the same trap |
| Stepping in place on the wall (the whole robot slips down a notch each time a leg lifts) | First tell where the loss is: mark a dot next to a stance cup on the glass and walk 3 cycles — the mark stays put while the body sinks = elastic ratchet: the 08-20 quantification put 83% of the slip in the instant of seal rupture during venting (venting slowly doesn't help), so the first choice is `--handover` (zero-force handover before the vent; starting value = measured single bounce × 0.8, docs/en/HANDOVER-DESIGN.md, calibrate δ with body_lean A/B in place); `--sag-comp` is a symptomatic layer that catches up after the drop (§4.5), and only one of the two runs during the handover A/B; the mark travelling with the cup = interface slip, clean the glass and the lip with alcohol and watch the "盘差" (worst cup pressure) field in the status line (cup pressure that can't be pushed past -75 with the pump never stopping = shallow vacuum, and both normal force and lateral stiffness are discounted); in tankless mode attachment is slow and creep takes a large share of the time, which improves noticeably once the tank is installed |
| The whole robot rocks at the instant a foot lifts | The CG wasn't moved far enough before release and that leg is still carrying load; check the support polygon computation |
| One servo gets hot after a few steps | Continuous load on the wall is normal, but one leg clearly hotter = uneven load sharing or residual fighting; find the leg by comparing current curves |
| Pi reboots on the wall | Undervoltage = a crash-level accident. Stop immediately, check the independent 5V supply and `get_throttled`, and stay off the wall until it is fixed |
| The whole robot dies at startup after the valve coils light up one by one (LED green → solid red, SSH drops, intermittent) | **Settled on the real robot 09-03 (lean_20260903_135325.log): the trigger is the servo relay closing, not the valves** — while the six coils were energized one by one, the 5V stayed flat at 4.88–4.89V with thr=0x0; `servo relay closed` (`舵机继电器已合闸`) is the last line, and it died <50ms later. Solid red = the halt state where the Pi 5's PMIC has cut power to the SoC (same as after `halt`; it needs a power cycle). The root cause is margin: the Pi's 5V input is only 4.89V unloaded (a healthy buck should give 5.05–5.15; `get_throttled=0` cannot show this kind of "not over the line but no margin left"), and 18 servos powering up at the same instant tug the shared 2S battery over the line. The root fix is in the supply: measure under load at the Pi's USB-C end and tune the buck output to 5.1–5.2V; swap in a short thick USB-C cable; put ≥1000µF electrolytics across both the buck's input and its output; verify that the servo return ground goes straight back to the battery negative and does not detour through the Servo2040's USB ground. Software mitigation (done): `enable(True)` is split in two — close the relay (powered, no torque) → 0.4s → firmware enable (torque), with the black box sampling the bus in each segment (`合闸后 x s` / `使能后 x s`, "x s after relay closure" / "x s after enable"), so the next death can be told apart as an inrush from powering up versus from producing torque. Forensics tools: run `bash scripts/pi_forensics.sh setup` once (it makes kernel logs persistent and must be run **before** the crash), then power-cycle after a reproduction and run `pi_forensics.sh check`; the black box writes `TLM 电源 5V=…` ("TLM power 5V=…") every 0.1s (`vcgencmd pmic_read_adc`; the user must be in the video group). The Pi 5 has no RTC battery, so the start time in the boot list is a fake clock saved last time (it can be off by hours); `check` back-computes the real boot time from the true timestamp of the last log line. **Added 09-04**: after the buck was swapped for an adjustable module set to 5.19V (the PMIC reads 5.105V, already at the level of the official supply), walk_teleop still died at startup (walk_teleop had no black box then; it has since been added, tag=walk/voice) — the static voltage is not the root cause; it is a sub-millisecond dip / ground bounce at the instant of relay closure, invisible to 10Hz sampling and to a multimeter; `/proc/device-tree/chosen/power/power_reset`=2 was read both times and was taken, per the Raspberry Pi engineers, as the PMIC's own testimony that the previous boot was cut for low voltage; **control on 09-06: it still reads 2 after several normal poweroffs/reboots, so on this machine it has no discriminating power and does not count as evidence** (the solid red LED after death already says the PMIC cut the SoC; a kernel crash does not turn the LED red). The battery is an unprotected 2S RC LiPo with no protection board, so there is no over-current trip and battery sag is not the prime suspect; **verdict on the evening of 09-04 (case file `html/en/pi-crash-ground-loop-20260904.html`)**: ① the user found that every walk_teleop run turns the sticky bits from 0x0 to 0x50000, even when nothing dies — the intermittent fatal event now has a deterministic non-fatal stand-in, so the experimental criterion becomes "do the bits get set or not"; ② walk_20260904_215456.log: 14ms after GPIO17 went high, thr=0x50005, with the servo bus at 0.00A at that moment; after enable it drew 6.67A and the battery went 7.71→7.31V while the Pi's 5V didn't budge — it is not the servos' large current, it is the instant of relay closure; ③ an A/B within a single boot, closing the relay with the GPIO17 script only: with the Pi↔Servo2040 USB cable unplugged, ten closures all gave 0x0; plugged back in, the very first one gave 0x50000 — **the path is the USB ground loop**; ④ the new buck is an XL4015 5A CC/CV board whose back-side R050 low-side sense resistor sits in the Pi's ground return, and its blue LED flashing green at the instant of closure = the module itself also sees this pulse (an aggravating factor; the old fixed module had no such resistor and died too, so it is not the root cause). Mechanism: the contacts closing charge the capacitance of 18 servos + the Servo2040 with a hundred-microsecond, tens-of-amps pulse that creates a voltage difference along the servo return ground; part of it flows through the USB ground → the Pi's ground plane → the GND Dupont jumper → R050 back to the battery negative, and the drop across the jumper + R050 looks to the PMIC exactly like a 5V dip. Remedies (not installed yet; the criterion is still the sticky bits): a USB isolator (full-speed, ADuM3160 class) is the cleanest; pre-charge / soft start on the servo rail (a small relay in series with 4.7Ω 5W closing 100ms first, or a P-MOS soft start; a manual pre-charge with 10Ω across the contacts can verify it first); a star ground can only reduce it. A capacitor across the Pi's 5V is only symptomatic (2200µF at 0.7A holds 0.4V for about 1ms). **Sequel 09-06 (case file section 08)**: with an ADuM3160 isolator fitted, ten GPIO17 closures all read 0x0, so the USB path is confirmed cut, yet body_lean still died tens of ms after closure (lean_20260906_234509.log ends at "relay closed", the 0.05s post-closure sample never came); island test: power off, disconnect the buck's IN−, Pi GND to battery negative reads open → the Pi side reaches the battery side through the buck alone, so the ground loop is not the only entry (YYNMOS-8 IN−/DC− optocoupler isolation was already measured on the pneumatic-electrical page); the remaining entry is the buck itself: the XL4015 module needs input ≥ output + 1.5V = 6.7V, the 2S pack sits at 7.70V under the valve load / 7.31V with servos enabled, under 1V of margin, and the closure pulse (30A × 30mΩ ≈ 0.9V and up) pulls it under; closure alone (valves off) is clean ten times while the real scripts (six valves energized) die, the difference being exactly that the valve load pulls the battery down first; remedy = replace the buck with a low-dropout synchronous buck (holds 5.1V with input a little over 6V, ≥5A, dropout <0.5V) or a buck-boost, keep the isolator, pre-charge demoted to secondary, input capacitor + Schottky not recommended; after the swap run the real scripts several times, criterion = no sticky bit + no death; **09-07 software stopgap**: all four startup scripts gained `--relay-first`, which closes the relay as soon as the serial port is open (valve coils not yet energized, the battery carries only the Pi) while firmware enable stays after the valves; run with it before the buck swap, and it doubles as an A/B: if it still dies with the relay first, "the valve load eats the margin" does not hold; **09-07 result**: the first relay-first run (body_lean --no-tank) died tens of ms after closure (last line 0.452s "relay closed", valve coils not energized, 5V 5.101V, serial port opened 0.25s earlier), "the valve load eats the margin" is withdrawn, trigger = closure itself; after the isolator the closure-only script died 1 in 11, the real scripts 3 in 3, remaining differences = serial port open + the Pi's own load (power-watch subprocesses / fsync per line); next: power the Pi from a power bank and run three times to settle it (bus readings come from the Servo2040 over serial, the Pi side can float with no ground wire): alive = the entry is the Pi's 5V source → buy the low-dropout synchronous buck, dies = unrelated to conducted power → prime suspect the serial link, then the closure-only script with the serial port open as a control; **located on the evening of 09-07**: the Pi moved to a power bank (the relay module's coil side DC+/DC− must move to the Pi header 5V/GND; on the buck OUT± the IN1 signal has no return path and the relay does not move), nothing else changed, closure no longer kills it (run count / sticky-bit readings to be added) → entry = the Pi's 5V source (XL4015 with no margin on 2S), the serial link and the Pi's own load are cleared; the mechanism (pulse pulls the battery → buck input below 6.7V → output collapses → PMIC cuts) is still inference, confirmed only by a scope on the buck input and output together; remedy = low-dropout synchronous buck / buck-boost, or a small separate battery for the Pi; the conclusion has been revised four times (power_reset withdrawn, XL4015 8V → 1.5V headroom, one path → two entries, valve load withdrawn), each by a control experiment, and the present one likewise awaits a scope check; **full-battery control, evening of 09-07**: battery fully charged, Pi back on the XL4015, nothing else changed, a real script stood up and get_throttled=0x0 (not even "undervoltage occurred") — same buck, three deaths in three at 7.3~7.9V versus 0x0 on a full battery pins the entry to the battery → buck → Pi path and clears the serial link; the power-bank run is confirmed: relay coil side moved to the Pi header 5V/GND (not one wire between the Pi side and the battery side), a real script was run and did not die, run count / sticky bit not recorded; after reconnecting, the Pi's 5V/GND and the relay DC+/DC− go together to the buck OUT±; a full battery is not a remedy, one session drops it back to 7.6V and into the zone where it dies, so before the swap measure the battery before powering up and do not start below 8.0V |
| Energizing the valve makes it fail to hold | The NC valve's ports are connected backwards (inlet / outlet / exhaust) or `VALVE_ON_LEVEL` has the wrong polarity |
| Pressure drops fast during the powered-off hang | Localize it with section-by-section leak testing; add epoxy at the joints; clean the lips; re-check the tank volume |

## Safety

- **The safety line never comes off**, including the inclined levels; load-test the anchor with a human drop first; leave the line slightly slack so it doesn't affect the gait.
- Cover the whole area directly below the working surface with mats; first climb at 0.3m height.
- During the powered-off hang test a person stands beside the robot, hands ready but not touching.
- Never force any joint by hand while the servos are enabled (35kg·cm strips gears); cut servo power before adjusting the pose —
  the NC valves keep the adhesion, so the robot won't fall.
- For any anomaly on the wall (hiccup, FAULT cascade, odd noise, heat), freeze the pose and observe first; don't rush to keep walking;
  a frozen attached state is the safe state, moving around blindly is what's dangerous.
- LiPo rules same as P0–P3: never leave it charging unattended, keep the XT60 within reach to yank, power down before rewiring.

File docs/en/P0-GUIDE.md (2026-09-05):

> English translation of [`docs/P0-GUIDE.md`](../P0-GUIDE.md). The Chinese original is the maintained source; if they differ, the Chinese version wins.

# P0 Preparation Stage · Detailed Operating Guide

Goal (1–2 weeks): **batch-1 parts arrive, the Pi 5 software environment is all green, and one leg is assembled and can be swung under Pi control.**
By the end of this stage you should be able to shoot a video: SSH into the Pi, type a command, and a spider leg on the desk lifts and sets back down.

The steps can run in parallel: finish step 1 (ordering) the same day, and do step 2 (Pi environment) and step 3 (printing) while you wait for the shipping.

---

## Step 1 · Order the batch-1 parts (day 1)

Follow the specs in tables 1 and 2 of `BOM.md`. This batch's list, and the points that must be confirmed with the seller before ordering:

| # | Part | Qty | Confirm before ordering |
|---|---|---|---|
| 1 | 35kg·cm digital servo (DS3235 / ZOSKAY class) | 4 | ① the **180° control angle** version (not 270°) ② operating voltage range includes 7.4V ③ comes with horns and screws |
| 2 | Pimoroni Servo2040 | 1 | genuine (buying agent / overseas order; longest lead time, so order it first) |
| 3 | 5V/5A DC-DC buck converter | 1 | input range covers 6–8.4V; one with a USB-C port is handier for feeding the Pi directly |
| 4 | 2S LiPo 5000mAh+ with XT60 + B3 charger | 1 each | battery with a protection board, or bring your own low-voltage alarm |
| 5 | 555 dual-head vacuum pump 12V | 1 | ultimate vacuum ≤-75kPa |
| 6 | 3/2-way solenoid valve 12V | 2 | **normally-closed type** (unpowered = air path cut, vacuum held) — get it confirmed in writing |
| 7 | 30mm 2.5-fold bellows vacuum suction cup | 3 | with an **M5 through-hole fitting + 90° barbed elbow** (air passes through the center of the stud) |
| 8 | XGZP6847A pressure sensor 0 to -100kPa | 1 | the analog-output version (not the I2C version) |
| 9 | ADS1115 module | 1 | — |
| 10 | 8-channel MOSFET driver board | 1 | the opto-isolated version is better |
| 11 | XL6009 boost converter module | 1 | — |
| 12 | 4×6mm silicone tubing 5m + 4mm tees / unions / check valves | 1 set | — |
| 13 | M1.6×6 hex socket screws (pack of 100), M2.5×6, M3 | 1 pack each | M1.6 is the workhorse for horn-to-printed-part joints |
| 14 | Dupont jumpers, XT60 pairs, 16AWG silicone wire, heat-shrink | as needed | — |

Budget total about ¥600–950. Batch 2 (the 15 servos and so on) is **not bought at this point**.

## Step 2 · Pi 5 software environment (days 1–3, no hardware needed)

1. **Flash the OS**: the official Raspberry Pi Imager → pick **Raspberry Pi OS Lite (64-bit)** →
   click the gear to preconfigure: hostname `spider`, enable SSH, fill in WiFi, username and password.
2. **First login and basic setup**:
   ```bash
   ssh <username>@spider.local
   sudo apt update && sudo apt install -y git python3-venv i2c-tools
   sudo raspi-config nonint do_i2c 0        # enable I2C (for the ADS1115)
   sudo usermod -aG dialout $USER            # serial port permission (for the Servo2040)
   # log out and back in for the group membership to take effect
   ```
3. **Deploy this repo**: push the repo from your dev machine to your git remote and clone it on the Pi,
   or just `rsync -a --exclude .venv --exclude .git ~/spider/ <username>@spider.local:~/spider/`.
4. **Install and verify the package**:
   ```bash
   cd ~/spider/software
   python3 -m venv .venv && source .venv/bin/activate
   pip install -e ".[sim,dev]"
   pytest tests/                             # expect: 18 passed
   python scripts/sim_walk.py --gif /tmp/walk.gif --seconds 2
   python scripts/stand_up.py --mock         # dry run, Ctrl-C to exit
   ```
   scp `/tmp/walk.gif` back and take a look: a hexapod tripod-gait animation means it passes.
5. **Power check habit** (do it every time from now on): `vcgencmd get_throttled` must print `0x0`;
   nonzero means undervoltage/throttling, so fix the power before going on.

## Step 3 · 3D printing (days 1–4, in parallel with shipping)

Print one **left front leg L1** (left front because that is the test channel in the software's default config: 15/16/17):

| File (`hardware/makeyourpet-hexapod/STL/`) | Qty | Notes |
|---|---|---|
| `left-coxa2.stl` | 1 | when several versions share a name, take the highest number (coxa2 > coxa) |
| `left-femur.stl` | 1 | — |
| `hardware/climbing-parts/left-tibia-suction.stl` | 1 | suction-foot integrated tibia (replaces left-tibia.stl; the cavity at the tip holds the cup directly) |
| `tip.stl` | 1 | plain foot tip (for the P0 swing test; can be fitted onto the old left-tibia) |
| `calibration-arm.stl` + `calibration-ruler.stl` | 1 each | the official servo calibration tools, needed for the ±45° pulse-width calibration in P1 |
| `hardware/climbing-parts/suction-foot-door.stl` | 1 | cup cavity door cover (glued shut with 502 super glue once the cup is in) |

Parameters: coxa/femur in PLA, 4 walls, 40% infill, 0.2mm layer height; for `left-tibia-suction.stl`
use PETG, 5–6 walls, 45% infill, printed **upright** (cup cavity facing down) + a brim ≥8mm, supports are fine for the tibia details;
`suction-foot-door.stl` goes outer face down, no supports. For part orientation and whether to add supports on the leg parts, follow the official
videos (YouTube channel **MakeYourPet**, leg assembly is episode 1); print the small assembly parts (limiter,
servo-back-hole2, etc.) as needed for the single leg in the video.
Dry-fit once before anything else: push the cup with its fitting into the cavity from the front; the rib should snap into the Ø15 groove, the two nuts should drop into the
hex pockets and not turn, and the door should close with no obvious slop. Too tight or too loose → change `gap_d`/`gap_hex`
in `tools/generate_climbing_parts.py` (by ±0.2mm) and reprint. Only glue the door with 502 super glue once it all checks out.

## Step 4 · Flash the Servo2040 firmware (the day it arrives, 5 minutes)

1. Download the community firmware:
   https://github.com/EddieCarrera/chica-servo2040-simpleDriver/releases/download/v0.0.1/chica-servo2040_release.uf2
2. **Hold the BOOT button on the board** while plugging in USB → an `RPI-RP2` drive appears on the computer → drag the .uf2 onto it → it reboots on its own and is done.
3. Verify: plug it into the Pi, `ls /dev/ttyACM*` should show a device; then:
   ```bash
   cd ~/spider/software && source .venv/bin/activate
   python -c "from hexapod.driver import Servo2040Driver; d=Servo2040Driver(); print('voltage', d.read_voltage_v()); d.close()"
   ```
   Servo power is not connected yet, so the reading depends on the "Separate USB & Ext. Power" jumper on the back of the board:
   not cut (factory default) reads about 5V (that is the USB 5V rail); already cut reads close to 0.
   Either way, if it prints a number the USB communication link is working.
   ⚠️ **That jumper must be cut before** connecting the 2S battery in step 5 (marked "CUT THIS!" on the wiring diagram),
   otherwise the battery's 7.4–8.4V back-feeds through the USB cable into the Pi and may destroy the Pi.

## Step 5 · Single-leg assembly (after the servos arrive, half a day)

⚠️ Order matters: **center the servos first, then fit the horns, then the structural parts** — get it backwards and the whole calibration is wrong.

1. **Mandatory checks before connecting the battery** (all three must pass before the battery may go on; do the first one with no power connected at all):
   - [ ] **Cut** the "Separate USB & Ext. Power" jumper on the back of the board (marked "CUT THIS!" on the wiring diagram).
         Connect a 2S battery without cutting it and the battery voltage back-feeds through the USB cable, destroying the Servo2040 and the Pi's USB port.
   - [ ] **Verify the cut**: with USB only and no battery, run the voltage read command from step 4 —
         a reading **close to 0** means the cut worked; still about 5V means it isn't cut all the way through, so go back, finish the cut, and re-test.
   - [ ] **Measure with a multimeter** which battery pigtail / XT60 lead is positive and which is negative before wiring the EXT terminals; **do not go by wire color alone**
         (aftermarket pigtails occasionally have red and black swapped, and reversed polarity kills the board instantly).

   Make it a habit: unplug USB before connecting or disconnecting the battery; the two power paths are never plugged or unplugged at the same time.
2. **Wiring** (against `hardware/makeyourpet-hexapod/wiring-diagram-servo2040.png`):
   the 3 servo signal wires go to Servo2040 channels **15 (coxa) / 16 (femur) / 17 (tibia)**;
   servo power comes from the 2S battery per the official wiring diagram (in P0 the relay can be left out and wired directly, but fit an XT60 quick disconnect).
3. **Center**:
   ```bash
   python scripts/servo_center.py            # center all channels at 1500µs and enable
   ```
   Hearing the servos lock means it worked. **Do not** force the servos by hand at this point.
4. **Fit the horns**: press each horn onto the spline at the center angle from the official video and tighten the retaining screw —
   the center poses of coxa/femur/tibia correspond to the official mounting offsets -8°/35°/68° (the video shows the alignment).
5. **Fit the structural parts**: assemble coxa → femur → tibia in that order (video episode 1), with M1.6 screws joining horns to printed parts.

## Step 6 · Swing test and acceptance (1 hour)

```bash
python scripts/servo_center.py                       # center reference
python - <<'EOF'                                     # sweep each of the three joints ±20°
import time
from hexapod.driver import Servo2040Driver
d = Servo2040Driver()
d.set_all_pulses_us([1500]*18); d.enable(True); time.sleep(1)
for ch in (15, 16, 17):
    for us in (1280, 1720, 1500):
        d.set_pulses_us(ch, [us]); time.sleep(0.8)
d.close()
EOF
```

**P0 acceptance checklist**:

- [ ] All batch-1 parts arrived; NC valves / 180° servos / M5 through-hole fittings checked against the physical items
- [ ] Pi: all 18 `pytest` items pass, `sim_walk.py` produces the GIF, `get_throttled` = 0x0
- [ ] Servo2040 firmware flashed, the Pi can read the voltage
- [ ] Power jumper cut (with USB only, the voltage reads close to 0), battery polarity confirmed with a multimeter
- [ ] All three joints of the single leg swing smoothly on command — no jitter, no odd noises, nothing loose in the structure
- [ ] Cup + fitting pushed fully home into the `left-tibia-suction.stl` cavity, nuts seated in the hex pockets and not turning, door cover dry-fits with no slop
- [ ] Whole-leg weight recorded (write it into `docs/en/weight-log.md`; budget reference: one leg with servos ~230g)

All ticked → move on to P1 (adhesion bench validation).

## Common problems

| Symptom | What to do |
|---|---|
| `/dev/ttyACM0` doesn't exist | Try another cable (many USB-C cables are charge-only); confirm the firmware flashed (rainbow chase on the board LEDs = waiting for a connection) |
| Permission denied opening the serial port | The `dialout` group hasn't taken effect — log out and back in; or temporarily `sudo chmod 666 /dev/ttyACM0` |
| Board/Pi smoking or unresponsive after the battery goes on | Most likely the jumper wasn't cut and battery voltage back-fed, or the battery polarity is reversed. Disconnect the battery and unplug USB immediately; on another computer hold BOOT and see whether the board still enumerates as `RPI-RP2`; test each Pi port in turn with a known-good device |
| Servos don't move but communication is fine | Forgot `enable(True)` (the RELAY enable); or servo power isn't connected / the battery is flat |
| Servo jitter / buzzing | If the 2S voltage is below 6.8V, charge it first; route signal wires away from power wires; jitter under the load of one leg is abnormal, so swap in the spare servo to isolate it |
| Horn angle isn't accurate after centering | The horn spline is toothed, so fit the nearest tooth and correct the residual later with `attach_deg` in `config.py` |
| Pi reboots or throttles often | `get_throttled` nonzero: switch to a 5V/5A supply, don't run the Pi off a computer USB port |
| Cup won't push into the cavity / nuts won't seat in the hex pockets | The printed part's XY tolerance is too tight: add 0.2 to `gap_d`/`gap_hex` and reprint, or file it out; if it's loose and rattles, subtract 0.2 |

## Safety

- Never leave a LiPo charging unattended; use a B3/B6 balance charger. Fit an XT60 quick disconnect on the test bench and cut power at the first odd noise.
- A 35kg servo has huge stall torque: keep fingers out of the joint's range of motion while it is powered.

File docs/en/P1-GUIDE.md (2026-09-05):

> English translation of [`docs/P1-GUIDE.md`](../P1-GUIDE.md). The Chinese original is the maintained source; if they differ, the Chinese version wins.

# P1 Adhesion System Bench Validation · Detailed Operating Guide

Goal (weeks 2–5): **get the whole vacuum chain "pump → tank → valve → cup + sensor → Pi" working on the bench,
and collect the first batch of measured data on whether climbing is feasible.**
By the end of this stage you should be able to shoot a video: a single suction-cup foot on vertical glass holding a 3kg weight without budging;
SSH into the Pi, type one command, and it completes an "attach–confirm–release" cycle (<2s).

Suggested order: step 1 doesn't depend on the pneumatic parts and can be done as soon as the servos are on; steps 3–7 strictly in order (each one is the prerequisite for the next);
steps 8–9 are the main event that produces the data.

---

## Step 1 · Single-leg ±45° pulse-width calibration (finish it while waiting for the pneumatic parts)

P2's `single_leg_wall.py` does single-leg IK, and calibrating leg L1 (channels 15/16/17) is the prerequisite for it.
The procedure is in "calibration procedure" in `software/README.md`; here are the extra bench details:

1. Confirm the **servo supply voltage** once more: it must not exceed the limit on the servo's label (the 6.8V version must be given 6.0–6.5V
   through a buck converter, never 2S direct).
2. Find the actual pulse widths for -45°/+45° joint by joint; pick one of two methods:
   - **Method A (no disassembly, recommended)**: stick a phone level on the leg segment. Center first and note the reference angle,
     then nudge the pulse width until the segment has turned ±45° relative to that reference. Use the level for the pitching joints (femur/tibia);
     for the coxa, which swings horizontally, use a paper protractor printed out and laid underneath.
   - **Method B (more accurate, more work)**: take the printed leg segments off, fit the `calibration-arm` printed in P0 onto the horn,
     and use it with `calibration-ruler` as shown in the official video to find the ±45° marks.
   Nudge the pulse width from an interactive Python session:
   ```bash
   cd ~/spider/software && source .venv/bin/activate && python
   >>> from hexapod.driver import Servo2040Driver
   >>> d = Servo2040Driver(); d.set_all_pulses_us([1500]*18); d.enable(True)
   >>> d.set_pulses_us(16, [1520])   # femur=16, close in slowly in ±10µs steps
   ```
3. Put the measured values into `us_m45/us_p45` for L1 in `config.py`; if the direction is reversed set `sign=-1`,
   and trim the zero-position residual with `attach_deg`. After the edits `pytest tests/` must still be all green.
4. Re-check: command femur to 0° and to +45°; a measured error of <2° on the level passes.

## Step 2 · Incoming inspection of the pneumatic parts (the day they arrive)

| Part | What to check |
|---|---|
| 3/2-way solenoid valve | 12V, labeled "normally closed" — the real behavior gets measured in step 3, don't just trust the listing |
| 30mm bellows suction cup | the fitting is an **M5 through-hole** type (air passes through the center of the stud) + a 90° barbed elbow; miss either and `suction_foot` cannot be assembled |
| XGZP6847A | the **analog-output version** (3 wires: 5V/GND/Vout), not the I2C one; range 0 to -100kPa |
| 555 dual-head pump | 12V, rated ultimate vacuum ≤-75kPa; two suction heads, which can be paralleled with a tee to pump down faster |
| Check valve | the body has a flow-direction arrow |
| 8-channel MOSFET board | trigger level compatible with 3.3V (for the opto version read the description; "high-level trigger 3-24V" is fine) |
| XL6009 | the adjustable version (with a potentiometer) |

## Step 3 · Measure the solenoid valve's behavior (half an hour; it decides the plumbing, the software polarity, and one design assumption)

The design doc assumes "an NC valve unpowered = the cup keeps its vacuum" (the passive-safety design in `CLIMBING-DESIGN.md` §2).
But plenty of the 0520B-class "normally closed" 3-way valves on the market actually **vent the outlet port to atmosphere when unpowered** — if that is what yours does, hanging
through a power loss doesn't hold up. This step is about pinning down exactly what the valve you bought does:

1. Measure the coil resistance with a multimeter (a few tens of Ω is normal); a "click" when 12V goes on means the coil works.
2. Test connectivity by **blowing through it**: label the three ports P (to the tank / vacuum side), A (to the cup side), R (exhaust).
   Blow into each port with the coil unpowered and then powered, and record which two ports are connected:

   | State | Measured connection |
   |---|---|
   | Unpowered | ___ ↔ ___ |
   | Powered | ___ ↔ ___ |

3. Compare against the conclusions:
   - **Ideal** (unpowered A↔P, or A fully sealed): holding vacuum without power works, so plumb it this way.
   - **Common** (unpowered A↔R, vented to atmosphere): the P1 bench work is unaffected and goes ahead as usual (just keep the valve powered during the data tests),
     but record the measurement in `CLIMBING-DESIGN.md` §4 — it has to be solved before P4
     (switch to a valve type / plumbing that holds when unpowered, or rewrite the safety argument for hanging through a power loss).
4. Either way, write down whether **connecting the cup to vacuum** corresponds to the coil being powered or unpowered — that decides the `VALVE_ON_LEVEL`
   constant in step 7.

## Step 4 · 12V supply and the MOSFET drive chain (half a day)

1. **Set the XL6009 voltage**: feed the input from the 2S battery (check polarity with a multimeter first), turn the potentiometer to
   12.0V output **with no load**, and only then connect the load. The P1 load (1 valve + 1 pump) is about 1A, so a 3A module is plenty.
2. **Wire the MOSFET board**: on the power side VCC = 12V, and its GND **shares a common ground** with the Pi's GND; on the control side
   IN1 ← Pi GPIO5 (valve), IN7 ← GPIO20 (pump), matching
   `VALVE_PINS[0]=5` and `PUMP_PIN=20` in `adhesion.py` (wire it differently and you change the constants to match).
3. Leave the valve and pump disconnected at first, and pulse the GPIOs while watching the board's indicator LEDs / output terminal voltage:
   ```bash
   sudo apt install -y python3-lgpio gpiod
   pip install lgpio smbus2        # i.e. the [pi] extra in pyproject
   python - <<'EOF'
   import lgpio, time
   h = lgpio.gpiochip_open(0)      # if it errors, try 4; gpioinfo | grep pinctrl-rp1 confirms the number
   for pin in (5, 20):
       lgpio.gpio_claim_output(h, pin, 0)
       lgpio.gpio_write(h, pin, 1); time.sleep(1); lgpio.gpio_write(h, pin, 0)
   lgpio.gpiochip_close(h)
   EOF
   ```
4. Once that passes, connect the valve and pump and pulse again: the valve clicks, the pump spins.

## Step 5 · Pressure sensing chain (half a day)

The XGZP6847A outputs 0.5–4.5V, above the Pi's 3.3V world, so it **must be divided down** before the ADS1115:

| Connection | Notes |
|---|---|
| XGZP 5V / GND | to Pi pins 2 (5V) / 6 (GND) |
| XGZP Vout → 10k → A0, A0 → 10k → GND | 1:1 divider, 4.5V→2.25V |
| ADS1115 VDD/GND | to Pi 3.3V / GND (**VDD goes to 3.3V, not 5V**) |
| ADS1115 SDA/SCL | Pi pins 3 / 5 (I2C1) |
| ADS1115 ADDR → GND | address 0x48 |

1. `i2cdetect -y 1` should show `48`.
2. Read the voltage:
   ```python
   from smbus2 import SMBus
   import time
   def read_a0_v(addr=0x48):
       with SMBus(1) as bus:
           bus.write_i2c_block_data(addr, 0x01, [0xC3, 0x83])  # A0 single-ended, ±4.096V, single-shot
           time.sleep(0.01)
           hi, lo = bus.read_i2c_block_data(addr, 0x00, 2)
           raw = (hi << 8) | lo
           return (raw - 65536 if raw > 32767 else raw) * 4.096 / 32768
   print(read_a0_v() * 2)   # ×2 = the sensor voltage before the divider
   ```
3. **Two-point calibration**:
   - At atmosphere, record the sensor voltage `V_ATM` (on the 0 to -100kPa version it should be close to 4.5V);
   - pull down to the pump's limit by hand (or with the pump once step 6 is built); the voltage should move monotonically toward the other end.
     Use the two points (V_ATM, 0kPa) and (limit voltage, near the pump's rated -75kPa) to confirm the sign of the slope;
     the nominal full-scale slope is 100kPa/4V = 25: `kPa = 25 × (V − V_ATM)` (for the batches whose voltage falls as it pumps down),
     and if the direction is reversed take the slope negative. The vacuum level must come out as a **negative** number.
   - Write `V_ATM` and the slope down; they get filled in at step 7.

## Step 6 · Assemble the vacuum circuit + manual verification (no software, half a day)

The P1 single-foot circuit (the single-foot subset of the pneumatic diagram in `CLIMBING-DESIGN.md` §4):

```
pump(suction port) ← check valve ← tank(PET bottle) ← 3-way valve[P] ; 3-way valve[A] → tee ┬→ suction cup
                                                      3-way valve[R] = atmosphere          └→ XGZP6847A
```

1. **Vacuum tank**: a carbonated-drink PET bottle (it takes negative pressure; a plain water bottle collapses). Drill two holes in the cap for
   4mm tubing, and double-seal with hot glue + epoxy.
2. **Check valve direction**: the arrow (flow direction) points at the pump — i.e. it allows "tank → pump" pumping and blocks air flowing back in.
   Once fitted, stop the pump; if the tank pressure doesn't recover, it is in the right way round.
3. **Sensor position**: P1 has only one XGZP, so tee it in **between valve and cup** (the pressure in the cup branch
   is what acceptance is about). If you want to watch the tank pressure at the same time, buy another one (¥20; table 2 of the BOM lists 3–6 of them anyway).
4. All fittings: pushed fully home + locked with a cable tie; a wrap of PTFE tape on the barbed fittings doesn't hurt.
5. **Manual verification** (skip the software, isolate the problem): feed the pump 12V directly, press the cup onto wiped-clean glass,
   and watch the voltage reading from step 5 — it should get below -60kPa. If it doesn't, brush soapy water on the fittings to find the leak,
   or clamp the tubing section by section and bisect.

## Step 7 · Implement Pi5VacuumIO and bring it up (1–2 days)

Replace the `Pi5VacuumIO` placeholder class in `software/hexapod/adhesion.py` with a real implementation
(fill the constants in from the measurements in steps 3 and 5):

```python
class Pi5VacuumIO:
    """Raspberry Pi 5 hardware IO. P1 bench: 1 valve, 1 pump, 1 sensor; P4 expands to 6 valves, 2 pumps."""
    VALVE_PINS = [5]
    PUMP_PIN = 20
    VALVE_ON_LEVEL = 1     # GPIO level where set_valve(True)=cup connected to vacuum, per the step 3 measurement
    ADS_ADDR = 0x48
    V_DIV = 2.0            # 1:1 resistor divider
    V_ATM = 4.50           # atmosphere-point voltage measured in step 5
    KPA_PER_V = 25.0       # slope measured in step 5 (sign included)
    GPIOCHIP = 0           # change to 4 if it won't open

    def __init__(self, n_feet=1):
        import lgpio
        from smbus2 import SMBus
        self._lg, self.n = lgpio, n_feet
        self._h = lgpio.gpiochip_open(self.GPIOCHIP)
        for p in self.VALVE_PINS[:n_feet]:
            lgpio.gpio_claim_output(self._h, p, 1 - self.VALVE_ON_LEVEL)
        lgpio.gpio_claim_output(self._h, self.PUMP_PIN, 0)
        self._bus = SMBus(1)

    def set_valve(self, i, on):
        self._lg.gpio_write(self._h, self.VALVE_PINS[i],
                            self.VALVE_ON_LEVEL if on else 1 - self.VALVE_ON_LEVEL)

    def set_pump(self, on):
        self._lg.gpio_write(self._h, self.PUMP_PIN, 1 if on else 0)

    def _read_v(self, ch=0):
        import time
        self._bus.write_i2c_block_data(self.ADS_ADDR, 0x01, [0xC3 + (ch << 4), 0x83])
        time.sleep(0.01)
        hi, lo = self._bus.read_i2c_block_data(self.ADS_ADDR, 0x00, 2)
        raw = (hi << 8) | lo
        return (raw - 65536 if raw > 32767 else raw) * 4.096 / 32768

    def read_foot_kpa(self, i):
        return self.KPA_PER_V * (self._read_v(0) * self.V_DIV - self.V_ATM)

    def read_tank_kpa(self):
        # P1's single sensor sits in the cup branch, so tank pressure uses the same reading as an approximation
        # — the pump hysteresis is therefore off; on the bench drive the pump manually or leave it on; P4 restores hysteresis once the tank has its own sensor.
        return self.read_foot_kpa(0)

    def close(self):
        self._bus.close()
        self._lg.gpiochip_close(self._h)
```

After the edit run `pytest tests/` first (the mock path must be unaffected), then run the full state machine cycle on the bench:

```python
import time
from hexapod.adhesion import AdhesionController, FootState, Pi5VacuumIO
io = Pi5VacuumIO(n_feet=1); ctl = AdhesionController(io, n_feet=1)
io.set_pump(True); time.sleep(3)            # pull the tank down first (pump under manual control)
t0 = time.time(); ctl.request_attach(0)     # the cup should already be pressed on the glass by now
while not ctl.is_attached(0):
    ctl.update(0.02); time.sleep(0.02)
    if ctl.state[0] is FootState.FAULT:
        raise SystemExit("SUCKING timed out - did not attach, check the seal")
ta = time.time() - t0
print(f"attach confirmed {ta:.2f}s  pressure {io.read_foot_kpa(0):.1f} kPa")
time.sleep(3)
t1 = time.time(); ctl.request_release(0)
while ctl.state[0] is not FootState.RELEASED:
    ctl.update(0.02); time.sleep(0.02)
tr = time.time() - t1
print(f"release {tr:.2f}s  cycle total {ta+tr:.2f}s (acceptance target <2s)")
io.set_pump(False); io.close()
```

## Step 8 · The three data curves (vertical glass, 1 day)

Wipe the glass/tile clean with alcohol first. Pressure logging script (20Hz to CSV; scp it back to the dev machine afterward to look at):

```python
import time, csv, sys
from hexapod.adhesion import Pi5VacuumIO
io = Pi5VacuumIO(n_feet=1)
with open(sys.argv[1], "w", newline="") as f:
    w = csv.writer(f); w.writerow(["t", "kpa"]); t0 = time.time()
    while time.time() - t0 < 90:
        w.writerow([round(time.time()-t0, 3), round(io.read_foot_kpa(0), 2)])
        time.sleep(0.05)
```

| Curve | Action | Target | Measured |
|---|---|---|---|
| 1 Pump-down time | cup on the wall → open the valve, time it to -40kPa | <1s | ___ |
| 2 Leak rate | after reaching -40kPa stop the pump, put the valve in "hold", watch it come back | no higher than -20kPa within 60s | ___ |
| 3 Release time | switch the valve to vent → the cup can be lifted off with no resistance | <0.5s | ___ |

Troubleshooting a miss: curve 1 slow → parallel the two pump heads / shorten the tubing / pump the tank down first; curve 2 bad → soapy water to find leaks,
re-wipe the cup lip and the glass, re-seal the fittings; curve 3 slow → is the exhaust port blocked, and what is the tube diameter.

## Step 9 · Hanging weight, tilt angle, printed-part retest (1–2 days; the data P2's decision rests on)

**Safety**: nobody stands and no feet go directly under the weight, and put something soft on the floor; add weight in steps with water bottles / calibration weights; goggles recommended
(a cup letting go snaps back).

1. **Normal pull-off**: mount the glass horizontally, attach the cup to its underside, and hang weight downward step by step until it lets go.
   Theoretical reference ~35N (3.5kg) @ -50kPa. Record: ___ kg @ ___ kPa
2. **Shear pull-off**: glass vertical, cup attached, hang weight sideways until it lets go. Theory is about 50% of normal.
   Record: ___ kg @ ___ kPa
3. **Tilt tolerance** (it sets the climbing stride; the key input for `CLIMBING-DESIGN.md` §6):
   shim with 5°/10°/15°/20° wedges (printed or wooden) and do 10 attachments at each angle:

   | Tilt | Successful seals /10 | Pull-off force |
   |---|---|---|
   | 5° / 10° / 15° / 20° | | |

   Feed the conclusion back into §6: tolerance ≥15° → stride can be 40mm; only 10° → tighten to ~25mm.
4. **suction_foot printed-part retest**: run the cup fitting through the printed baseplate and lock the M5 nut (tightened through the side window),
   route the tube out of the side window from the barbed elbow, fit the whole foot onto the tibia's square shaft (locked with a set screw), and repeat curve 2 and the hanging weight.
   Air leaking between print layers → brush thin epoxy on the nut cavity and the inner face of the baseplate / seal the side window; not strong enough → add walls and reprint.
5. **Weigh it**: record the whole foot (printed part + cup + fitting + set screw) in `docs/en/weight-log.md`.

## P1 acceptance checklist

- [ ] L1 leg ±45° calibration entered in `config.py`, `pytest` all green, measured re-check <2°
- [x] Solenoid valve unpowered/powered behavior measured and on record; if "unpowered ≠ vacuum held", it is entered in the CLIMBING-DESIGN to-do list
- [x] `Pi5VacuumIO` implemented (GPIO polarity and the pressure conversion set by two-point calibration)
- [x] Curves 1/2/3 meet target: <1s to -40kPa; no recovery past -20kPa in 60s; release <0.5s
- [x] Normal/shear pull-off force and tilt-tolerance data complete, stride conclusion fed back into §6
- [x] **1.5kg hung on vertical glass (the 30mm cup's limit) for 10 minutes** (done with the complete suction_foot printed foot)
- [x] **"attach–confirm–release" cycle <2s** (run by the state machine, not by hand)
- [x] Whole-foot weight recorded in weight-log
- [ ] P2 materials ordered: L-frame stock, linear rail / drawer slide + carriage, 1.5kg of weight, a vertical glass panel

All ticked → move on to P2 (the single-leg climbing decision gate). The printer is idle during P1/P2, so you can start printing the whole robot's structural parts.

## Common problems

| Symptom | What to do |
|---|---|
| `i2cdetect` doesn't show 0x48 | SDA/SCL swapped; ADDR left floating (0x48 is the default, but tie it to GND to be sure); I2C not enabled (it was enabled in P0 — re-check with `raspi-config`) |
| Pressure reading never changes | Divider resistors not connected / wired to the wrong channel instead of A0; the sensor's 5V supply isn't connected |
| The state machine never reaches ATTACHED | The conversion sign is wrong — vacuum has to be negative; check the sign of `KPA_PER_V` |
| The valve doesn't actuate | Measure the actual 12V (the XL6009 sags under load); MOSFET trigger level and common ground; check whether the coil is open circuit |
| The pump spins but pulls nothing | Wrong port on the dual-head pump (suction vs exhaust); check valve installed backwards; a big leak at one of the fittings |
| The PET bottle collapses | Switch to a carbonated-drink bottle; or lower the tank's vacuum target to -60kPa |
| `lgpio.gpiochip_open` errors out | The Pi 5 chip number is 0 or 4 depending on the kernel version — confirm with `gpioinfo`; add the user to the `gpio` group, or use sudo |
| The pump never stops | With P1's single sensor `read_tank_kpa` is an approximation, so the hysteresis being off is expected; drive the pump manually during the bench phase |
| The cup drops as soon as power is cut | That's the valve type issue from step 3 (unpowered = vented to atmosphere), not a leak; see that step for what to do |
| The cup slips on the glass | Dust or oil on the lip or the glass — wipe both with alcohol; the vacuum isn't reaching -40kPa |

## Safety

- Kill the power before rewiring the 12V circuit; shorting the XL6009 output blows the transistor instantly.
- Valve and pump are inductive loads, so make sure the MOSFET board has flyback diodes (opto boards usually do; bare-transistor boards need you to add them).
- Hanging-weight tests: stay out from under the weight, add weight in steps, tape the glass edges so they don't chip.
- The pump heats up when it runs continuously against a dead head; keep a single test ≤5 minutes and let it rest if it feels hot.
- Same LiPo rules as P0: never charge unattended, keep the XT60 quick disconnect within reach.

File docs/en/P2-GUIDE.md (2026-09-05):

> English translation of [`docs/P2-GUIDE.md`](../P2-GUIDE.md). The Chinese original is the maintained source; if they differ, the Chinese version wins.

# P2 Single-Leg Wall Trial · Detailed Operating Guide

Goal (weeks 5–9): **the decision gate of the whole project — one leg, in front of vertical glass, automatically completes the
"extend → press → pump down → pressure confirm → take load → vent → lift" cycle and holds a 1.5kg weight on its own.**
By the end of this stage you should be able to shoot two videos: ① the rig running 50 attach/release cycles back to back; ② with the carriage's lock pin pulled,
the 1.5kg weight hanging entirely on the attached leg for 5 minutes without budging.

**Batch 2 is not bought** before this passes. Suggested order: step 1 (materials) goes first; step 4 (software dry run) doesn't depend on
the rig and can be finished while waiting for shipping; steps 2–3 build the rig, steps 5–6 are the main event, strictly in order.

Prerequisite check (all of these were finished in P0/P1; if one is missing, go back and do it first):

- [ ] L1 leg ±45° pulse widths + measured `attach_deg` values are in `config.py` (tibia 89.3 — re-measured with the new
      suction part on 2026-07-19, direction also swapped; femur 49.7, see `LEG-GEOMETRY-OPEN.md` §2.11/§2.12;
      the coxa can just use the official -8, this rig is insensitive to it, see step 2. ⚠ after changing a structural part or refitting a horn the calibration is void and must be redone)
- [ ] `Pi5VacuumIO` implemented and the three P1 curves meet target (<1s to -40kPa; leak doesn't pass -20 in 60s; release <0.5s)
- [ ] The cup is installed in the `left-tibia-suction.stl` cavity, the door cover is glued on, and the whole-foot hanging-weight retest passed (P1 step 9)

---

## Step 1 · Materials (1–2 days, mostly things you have around)

| # | Material | Spec / qty | Notes |
|---|---|---|---|
| 1 | Vertical glass panel | ≥400×400mm, ≥5mm thick | backed by a wood board the whole time; tape the edges so they don't chip |
| 2 | Post and base | 2020 aluminum extrusion or wood beam | weight the base down or clamp it to the table with a G-clamp |
| 3 | Drawer slide (three-section) | 300mm, rated ≥10kg | or a linear rail; must mount vertically and slide smoothly with no play |
| 4 | Carriage plate | wood/acrylic ~150×100 | mounted on the moving side of the slide; the leg base and the weights both go on it |
| 5 | Lock pin | 1 door bolt | switches the carriage between "locked" and "released"; must be pullable one-handed |
| 6 | Weights | make the total sliding mass 1.5kg | includes carriage plate + leg + base; trim with water bottles / barbell plates |
| 7 | Spring scale | 0–5kg | for the 1kg lateral pull acceptance |
| 8 | Cushion pad | towel / EVA mat | at the bottom of the slide travel, to cushion a fall if the cup lets go |
| 9 | Corner brackets and screws | as needed | stiffness is half of whether this rig works |

## Step 2 · Rig geometry (half a day to 1 day)

```
        post(vertical)                glass(vertical, backing board)
          │ ┌rail                            ║
          │ │┌carriage──coxa servo case═══╗  ║   coxa output shaft horizontal, pointing at the glass
          │ ││   +weight             femur ╲ ║
          │ ││lock pin↕                     ╲║ ← cup pressed on the glass
          │ ││                          tibia║
          ┴─┴┴──cushion──────────────────────║──
```

1. **Glass vertical**, wiped clean (alcohol), backing board clamped behind it.
2. **Fix the coxa servo case to the carriage plate**: output shaft horizontal, pointing perpendicular at the glass;
   the case's mounting face (the equivalent of the robot's body plane) sits **90mm from the glass**. Cut slots in the base for ±20mm of adjustment.
   > Why 90 and not the "about 130" written in the ROADMAP: 130 was a rough number thrown together from the "foot working radius"
   > before calibration; recomputed with the measured calibration + the physical cup axis (δ=22.7°, see step 4) (`CLIMBING-DESIGN.md`
   > §6 table A), at a stand height of 90mm and a stance-phase reach of 170mm the cup axis is off by only 1.6°.
   > The 90mm in this guide is what counts, and the constants in step 4's script are computed for it.
3. **Leg plane vertical**: with the coxa centered (1510µs), the femur/tibia swing plane should be plumb
   (eyeballing it plus a phone level against the side of the femur is enough; ±3° doesn't matter).
4. **An uncalibrated coxa doesn't affect this rig**: the coxa axis is ⊥ to the glass, so a γ error only swings the foot along an arc across the glass surface,
   leaving the cup axis's attitude relative to the glass normal completely unchanged (that is exactly the basis for pushing the γ measurement to P3,
   `LEG-GEOMETRY-OPEN.md` §5). If the leg reaching out at an angle bothers you, trim the coxa `attach_deg` in `config.py`
   to straighten it; the value doesn't have to be accurate.
5. **Stiffness acceptance**: push the leg base by hand; movement in any direction <1mm. The press-down reaction is tens of newtons,
   and if the frame is soft the preload travel gets eaten by deflection — that is suspect number one when it won't attach.
6. **Geometry self-check** (don't mount the glass yet): after confirming the software with `--mock` from step 4, command the press pose on the real hardware
   and measure with calipers from the plane of the cup lip to "the plane where the glass will be" — the lip should be **past** that plane by about 15mm
   (that is the press interference). If it is far off, use the slots to adjust that 90mm distance.

## Step 3 · Carriage load-bearing mechanism (half a day)

1. Mount the slide vertically on the post, carriage travel ≥50mm, cushion pad at the bottom.
2. The leg base + weights all mount on the carriage plate, and the **total sliding mass is weighed to 1.5kg** (≈ the 2.5kg whole robot ÷ 3
   effectively load-bearing feet, plus margin). Keep the weights as close to the slide's axis as possible; off to one side they bind the rail.
3. The lock pin has two states: **locked** (carriage fixed = a rigid rig, for running cycles) /
   **released** (carriage free to slide down = the whole weight transfers to the attached leg, for the load-bearing acceptance).
4. Rehearse "pull the pin one-handed, set the pin one-handed" once; while pulling the pin the other hand does not touch the carriage.
5. Rehearse a let-go (empty carriage, no leg): release it and let the carriage drop free onto the cushion pad, confirming nothing gets smashed at the end of travel.

## Step 4 · Software and dry run (finish it while the rig is being built)

The software deliverable is already in place: `software/scripts/single_leg_wall.py`.

**Geometry constants** (at the top of the script, computed for the 90mm rig from step 2):

| Constant | Value | Meaning |
|---|---|---|
| `FOOT_X` | 169 | foot radial position: when pressing, the **physical cup axis** is ⊥ to the glass (0.1° off) |
| `Z_LIFT` | -70 | lift-off position, lip 20mm from the glass |
| `Z_CONTACT` | -90 | lip just touching the glass (= the hip plane's distance to the glass) |
| `Z_PRESS` | -105 | press position = contact plus another 15mm (13.5 of preload travel + 1.5 of preload, measured in `LEG-GEOMETRY-OPEN.md` §4.4) |

> ⚠ **Why FOOT_X is 169 and not the 122 you get from "K→P perpendicular to the glass"**: the physical cup axis runs along the square shaft,
> and differs from the model's virtual line K→P by a fixed **δ=22.7°** (the knee axis K is not on the square shaft, `LEG-GEOMETRY-OPEN.md`
> §2.13). Press with K→P ⊥ to the glass (122) and the cup jams into the glass at a 22.5° tilt, past the 15° tolerance, and simply will not attach.
> Rig drawing: see `html/en/p2-rig-diagram.html`.

Quick reference for changing the constants when the rig distance isn't 90 (H = the measured distance from the case mounting face to the glass):
`Z_CONTACT=-H`, `Z_PRESS=-H-15`, `Z_LIFT=-H+20`; `FOOT_X`: H=80→168, 90→169, 100→169.
Across the whole cycle the physical cup axis deviates ≤4.5° from the glass normal, inside the 15° tolerance measured in P1, with ≥44° of travel margin.

1. **Mock dry run** (dev machine or Pi, either works):
   ```bash
   cd ~/spider/software && source .venv/bin/activate
   python scripts/single_leg_wall.py --mock --cycles 3
   # expect: all 3 cycles succeed, hold pressure around -40kPa, 100% success rate
   ```
2. **Options**: `--cycles N` number of cycles; `--hold SECONDS` how long each cycle holds the attachment; `--csv PATH` for the detail log
   (t/cycle/phase/kpa/amp at 20Hz — the pressure curve and the servo current are both in there); `--release` to clean up.
3. **Retry on failure** is built in: SUCKING timeout → lift 5mm → press again, up to 3 times; if all fail, that cycle counts as a failure.
4. **Ctrl-C means "freeze", not "stop"**: the valve stays where it is and the servos stay enabled — a carriage hanging on an attached cup
   must not fall just because you pressed Ctrl-C. Always clean up with:
   ```bash
   python scripts/single_leg_wall.py --release    # vent + return to the lift-off position
   ```
5. **Pump policy**: the script disables the state machine's pump hysteresis (with P1's single sensor the tank pressure reading is off, which makes the pump run long and get hot)
   and replaces it with "pre-pump 1.5s before pumping down + top up whenever the hold falls below -45kPa". The pump duty cycle is therefore very low,
   so 50 cycles back to back is no overheating worry.
6. Before the first run on real hardware, go through the old P0 rules again: jumper cut, battery polarity, `get_throttled` = 0x0.

## Step 5 · Staged ramp-up (1–2 days)

Pass each level before moving to the next; if any level fails, fix it before going on:

| Level | State | Command / action | Pass criterion |
|---|---|---|---|
| 1 | Locked + no weight | `--cycles 1 --hold 3` | succeeds first time; the attach time on screen ≈ P1's <1s |
| 2 | Same as above | `--cycles 10` | 10/10 success (built-in retries allowed) |
| 3 | Locked + weights on the carriage | `--cycles 5` | no structural deflection, success rate doesn't drop |
| 4 | **Released, taking load** | a single cycle with `--hold 300`; pull the pin by hand after the screen confirms attachment | 1.5kg hangs for 5 minutes without letting go, pressure stable |
| 5 | Lateral load | while under load, pull the carriage horizontally with the spring scale to 1kg and hold 10s | doesn't let go, doesn't slip |
| 6 | Torque margin | look at the CSV: the current peak at the instant of pressing vs the baseline during hold | the peak visibly has margin; deepen `Z_PRESS` by another 3mm and re-measure the current increase as a reference |

- Level 4 operating discipline: **never pull the pin until the screen shows attachment confirmed (≤-30kPa)**; stand to the side after pulling it;
  venting is only allowed after the pin is back in.
- Level 6 note: the Servo2040 reads the whole board's total current, which is an approximation — what matters is the relative change, not the absolute value.
  The criterion for the 35kg·cm servos derated to 50%: if the current rise stays gentle after 3mm more preload (no steep jump, no odd noise, no
  heating), the wall pose is taken to have margin; a steep jump means it is already close to the stall region.
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

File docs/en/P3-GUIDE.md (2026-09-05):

> English translation of [`docs/P3-GUIDE.md`](../P3-GUIDE.md). The Chinese original is the maintained source; if they differ, the Chinese version wins.

# P3 whole-robot assembly and floor walking · detailed operating guide

Goal (weeks 9–15): **assemble the 18-servo robot, finish calibrating every servo, get it walking on flat ground.**
Acceptance: walk 2m in a straight line on the floor, turn 360° in place, cross a 2cm obstacle, single-leg FK/IK point-to-point error <5mm;
weigh the whole robot into `weight-log.md` (reference line ≤1.9kg without the adhesion system; start weight reduction above 2.2kg).

The P2 decision gate **passed on 2026-07-22** (acceptance data below the checklist in `P2-GUIDE.md`).
Two tracks run in parallel in this stage: the **delivery track** (order in step 1, 1–2 weeks of waiting) and the **printing track** (step 2,
keep the printer fully loaded). Assembly (from step 3 on) starts once the two tracks meet.

Prerequisite check:

- [ ] P2 decision gate passed (2026-07-22 ✅)
- [ ] Pi 5 environment healthy: `pytest tests/` all green, `get_throttled` = 0x0, independent 5V/5A supply
- [ ] L1 leg calibration values in `config.py` (tibia 89.3 k baseline / femur 49.7 / coxa official -8, to be measured in P3)

---
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

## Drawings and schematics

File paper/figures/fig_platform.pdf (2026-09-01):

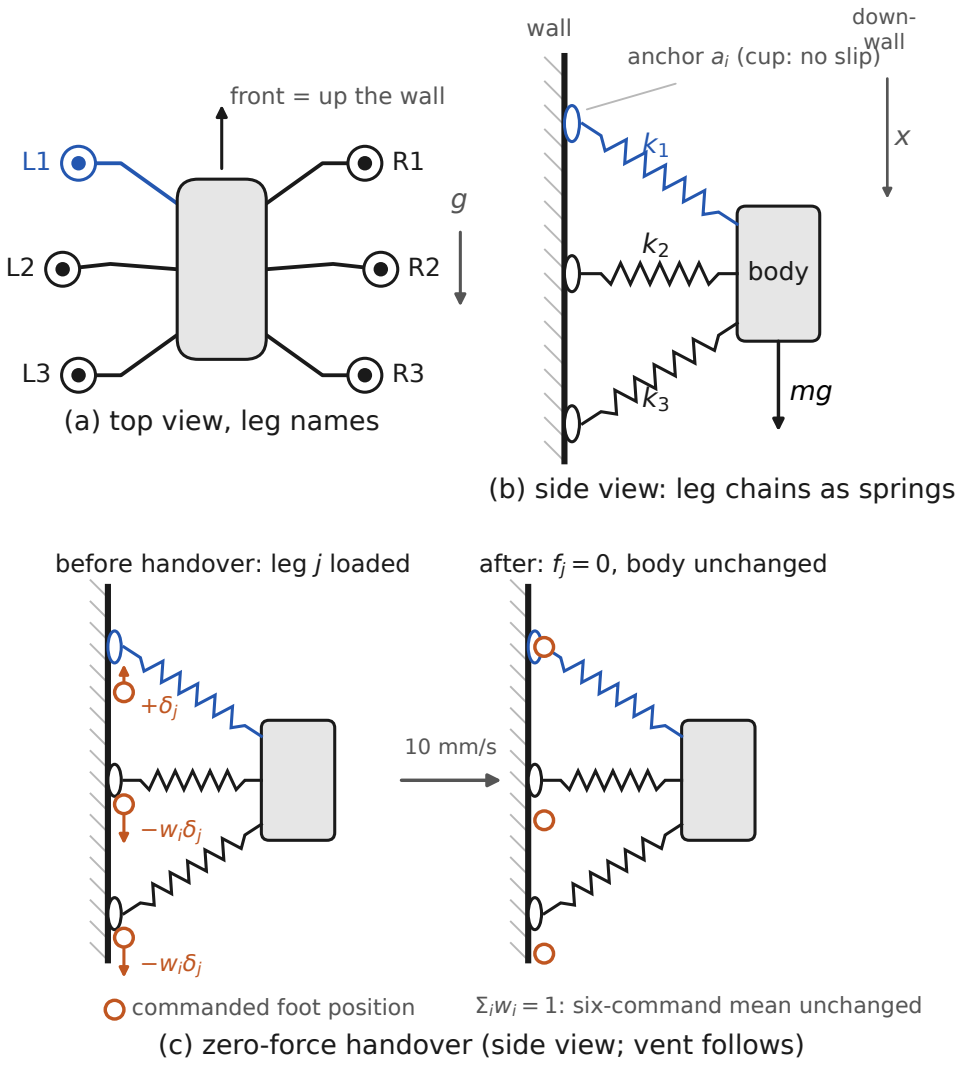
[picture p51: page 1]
wall; body; down- wall; −wiδj; before handover: leg j loaded; after: fj = 0, body unchanged; commanded foot position; Σiwi = 1: six-command mean unchanged

anchor ai (cup: no slip)

front = up the wall

(a) top view, leg names

(b) side view: leg chains as springs

−wiδj
(c) zero-force handover (side view; vent follows)

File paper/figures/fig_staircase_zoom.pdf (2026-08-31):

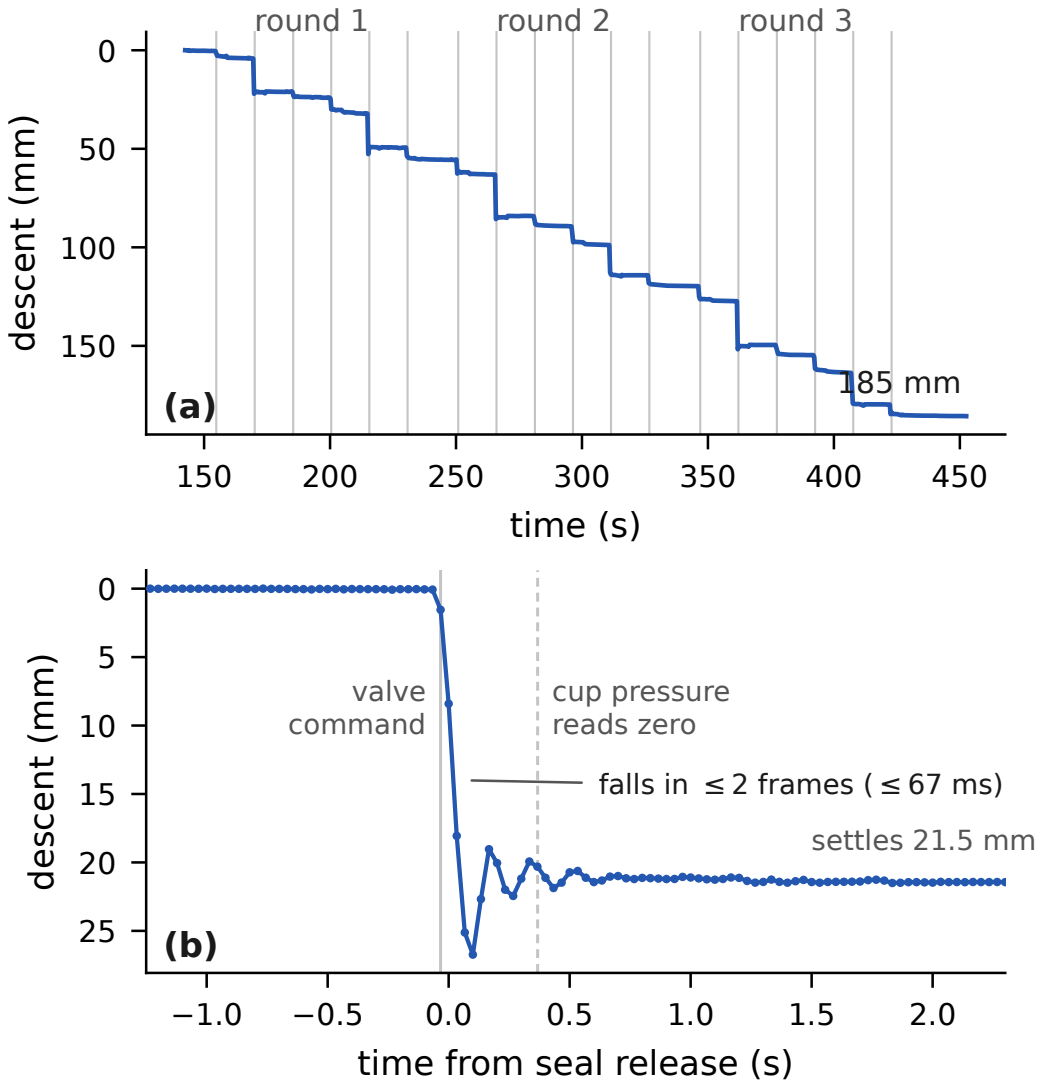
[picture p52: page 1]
time (s); descent (mm); round 1; round 2; round 3; valve command; settles 21.5 mm

cup pressure
reads zero
falls in ≤ 2 frames ( ≤ 67 ms)

time from seal release (s)

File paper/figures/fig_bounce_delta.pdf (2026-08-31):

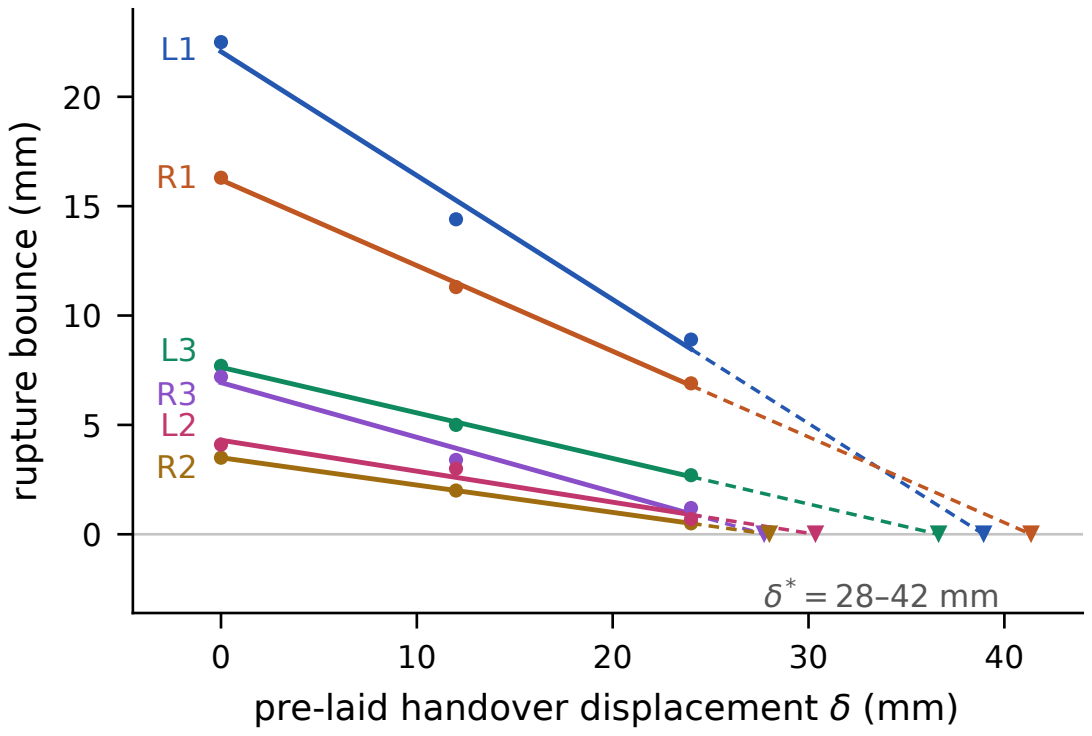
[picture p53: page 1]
40 pre-laid handover displacement δ (mm)

rupture bounce (mm)

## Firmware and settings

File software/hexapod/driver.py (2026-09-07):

"""Servo2040 驱动 —— Chica 串口协议。

协议从固件源码逐字节确认（EddieCarrera/chica-servo2040-simpleDriver，MIT）：

  SET 包:  0xD3, startIdx, count, [低7位, 高7位] * count
  GET 包:  0xC7, startIdx, count
  GET 响应: 0xC7, startIdx, count, 然后每项 [低7位, 高7位]

索引表（cmdPins）：0..17 舵机 SERVO1..18；18..23 足底开关 TS1..TS6；
24 电流；25 电压；26 RELAY（固件内部舵机使能；其 GPIO26 引脚 08-15 起悬空不接）；
27/28 A1/A2。

值均为 14 位。舵机值 = 脉宽 µs。换算（来自固件常量）：
  电压 V = raw / 310.3        电流 A = (raw - 512) * 0.0814

固件逐字节读取超时 100µs —— 一个数据包必须一次 write() 发完，不能分段。
上电后舵机不动，直到固件使能（arm）；先发好全部脉宽再使能，舵机会直接到位。

物理继电器（舵机 7.4V 总闸，切正极高边）08-15 定案改由 Pi GPIO17 驱动，
不再走 Servo2040 A0/GPIO26：enable() 串口 RELAY 指令照发（保固件使能），
功率通断由 GPIO17 收口。高电平吸合（模块跳线插 H 侧）；lgpio 进程退出后
GPIO 回输入态 → 继电器释放 → 舵机断电（常闭阀保真空），天然急停兜底。

合闸拆两步（09-03）：enable(True) = power_on()（只合 GPIO17，舵机带电但固件
未使能=无脉冲不出力）→ 等 ARM_DELAY_S → arm()（固件使能，18 舵机同刻开始向
目标位出力）。原先固件使能在前、合闸在后，带电冲击与出力冲击叠在同一瞬间：
09-03 实机黑匣子（lean_20260903_135325.log）合闸后 <50ms Pi 5 整机死机（5V
输入空载仅 4.89V，余量极薄）。拆开后两次冲击各自峰值更小，且黑匣子在中间
采样能分清是哪一记把 5V 拽过线。分闸顺序不变：先断功率再撤固件使能。
09-07 起启动脚本可 --relay-first 把 power_on() 提到六阀线圈通电之前
（hexapod/powerlog.py servo_relay_close），arm() 位置不变：合闸落在电池只带
Pi 的最轻载时刻，是换降压板前的止血兼 A/B。
"""
import time

SET_CMD = 0xD3
GET_CMD = 0xC7
IDX_SERVO1 = 0
IDX_TS1 = 18
IDX_CURR = 24
IDX_VOLT = 25
IDX_RELAY = 26
NUM_SERVOS = 18
NUM_TOUCH = 6

VOLT_RATIO = 310.3
CURR_LSB = 0.0814
TOUCH_THRESHOLD_RAW = 512  # 开关闭合到 3.3V ≈ 1023


def encode_set(start: int, values) -> bytes:
    values = list(values)
    assert 0 <= start and start + len(values) <= 29 and len(values) <= 127
    pkt = bytearray([SET_CMD, start, len(values)])
    for v in values:
        v = int(round(v)) & 0x3FFF
        pkt += bytes([v & 0x7F, (v >> 7) & 0x7F])
    return bytes(pkt)


def encode_get(start: int, count: int) -> bytes:
    return bytes([GET_CMD, start, count])


def decode_get_response(buf: bytes, start: int, count: int):
    """校验 3 字节包头并解出 count 个 14 位值。"""
    if len(buf) != 3 + 2 * count:
        raise IOError(f"GET 响应长度 {len(buf)}，期望 {3 + 2 * count}")
    if buf[0] != GET_CMD or buf[1] != start or buf[2] != count:
        raise IOError(f"GET 响应包头不符: {buf[:3].hex()}")
    return [(buf[3 + 2 * i] & 0x7F) | ((buf[4 + 2 * i] & 0x7F) << 7)
            for i in range(count)]


class Servo2040Driver:
    """通过 USB CDC 串口驱动 Servo2040（树莓派上通常是 /dev/ttyACM0）。"""

    RELAY_PIN = 17   # Pi GPIO17（Pin11）→ 继电器 IN1，高电平吸合（跳线 H 侧）
    GPIOCHIP = 4     # 树莓派 5
    ARM_DELAY_S = 0.4   # 合闸→固件使能的间隔（模块头"合闸拆两步"）

    def __init__(self, port: str = "/dev/ttyACM0", timeout: float = 0.2):
        import serial  # 延迟导入，无 pyserial 时仍可用 MockDriver
        import lgpio   # 物理继电器在 Pi GPIO17，缺 lgpio 时禁止静默降级
        self.ser = serial.Serial(port, baudrate=115200, timeout=timeout)
        time.sleep(0.2)  # 等固件退出 LED 等待循环
        self.ser.reset_input_buffer()
        self._lg = lgpio
        try:
            self._h = lgpio.gpiochip_open(self.GPIOCHIP)
        except Exception:
            self._h = lgpio.gpiochip_open(0)
        lgpio.gpio_claim_output(self._h, self.RELAY_PIN, 0)  # 初始必断

    # --- 输出 ---
    def set_pulses_us(self, start: int, values) -> None:
        self.ser.write(encode_set(start, values))

    def set_all_pulses_us(self, values18) -> None:
        assert len(values18) == NUM_SERVOS
        self.ser.write(encode_set(IDX_SERVO1, values18))

    def power_on(self) -> None:
        """只合物理继电器（GPIO17）：舵机带电，固件未使能=无脉冲不出力。"""
        self._lg.gpio_write(self._h, self.RELAY_PIN, 1)

    def arm(self) -> None:
        """固件使能：开始输出脉冲，18 舵机同刻向目标位出力。须先 power_on。"""
        self.ser.write(encode_set(IDX_RELAY, [1]))

    def enable(self, on: bool) -> None:
        # 合闸拆两步（模块头）：合继电器 → ARM_DELAY_S → 固件使能；
        # 分闸：先断功率再撤固件使能——通断始终由 GPIO17 收口
        if on:
            self.power_on()
            time.sleep(self.ARM_DELAY_S)
            self.arm()
        else:
            self._lg.gpio_write(self._h, self.RELAY_PIN, 0)
            self.ser.write(encode_set(IDX_RELAY, [0]))

    # --- 读取 ---
    def _get(self, start: int, count: int):
        self.ser.reset_input_buffer()
        self.ser.write(encode_get(start, count))
        buf = self.ser.read(3 + 2 * count)
        return decode_get_response(buf, start, count)

    def read_touch_raw(self):
        return self._get(IDX_TS1, NUM_TOUCH)

    def read_touch(self):
        """6 路足底开关 [TS1..TS6]，True=触地。按腿名取用 LegConfig.touch_idx-18。"""
        return [v > TOUCH_THRESHOLD_RAW for v in self.read_touch_raw()]

    def read_voltage_v(self) -> float:
        return self._get(IDX_VOLT, 1)[0] / VOLT_RATIO

    def read_current_a(self) -> float:
        return (self._get(IDX_CURR, 1)[0] - 512) * CURR_LSB

    def close(self) -> None:
        self.enable(False)
        self.ser.close()
        self._lg.gpiochip_close(self._h)


class MockDriver:
    """无硬件仿真/测试用：接口与 Servo2040Driver 一致，记录状态。"""

    is_mock = True   # 时序敏感调用方（如 glide_to）据此跳过真实墙钟等待

    def __init__(self):
        self.pulses = [1500.0] * NUM_SERVOS
        self.enabled = False
        self.powered = False   # 物理继电器（power_on）；enabled=固件使能（arm）
        self.touch_raw = [0] * NUM_TOUCH
        self.voltage = 7.4
        self.current = 1.0
        self.history = []  # [(t, pulses copy)]

    def set_pulses_us(self, start, values):
        for i, v in enumerate(values):
            if start + i < NUM_SERVOS:
                self.pulses[start + i] = float(v)
        self.history.append(list(self.pulses))

    def set_all_pulses_us(self, values18):
        self.set_pulses_us(0, values18)

    def power_on(self):
        self.powered = True

    def arm(self):
        self.enabled = True

    def enable(self, on):
        if on:
            self.power_on()
            self.arm()
        else:
            self.enabled = self.powered = False

    def read_touch_raw(self):
        return list(self.touch_raw)

    def read_touch(self):
        return [v > TOUCH_THRESHOLD_RAW for v in self.touch_raw]

    def read_voltage_v(self):
        return self.voltage

    def read_current_a(self):
        return self.current

    def close(self):
        self.enabled = self.powered = False

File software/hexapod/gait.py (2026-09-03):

"""步态引擎：相位式步态生成。

每条腿一个相位偏移 offset，全局相位 p = (t / cycle_time + offset) % 1：
  p < duty      支撑相（stance）：足端贴地，相对身体匀速后移
  p >= duty     摆动相（swing）：足端抬起，前移到下一落点

输出为各腿足端在**身体坐标系**中的目标点（默认站位 + 步幅偏移）。
"""
import math
from dataclasses import dataclass

from .config import RobotConfig, LEG_NAMES


@dataclass(frozen=True)
class Gait:
    name: str
    duty: float                 # 支撑相占比
    offsets: dict               # 腿名 -> 相位偏移 [0,1)


# 三角步态：L1/R2/L3 与 R1/L2/R3 交替，地面行走用
TRIPOD = Gait("tripod", 0.5, {"L1": 0.0, "R2": 0.0, "L3": 0.0,
                              "R1": 0.5, "L2": 0.5, "R3": 0.5})
# 波浪步态：一次一腿（后->前），慢但稳
WAVE = Gait("wave", 5 / 6, {"R3": 0.0, "R2": 1 / 6, "R1": 2 / 6,
                            "L3": 3 / 6, "L2": 4 / 6, "L1": 5 / 6})
# 爬墙步态：对角交替波浪（每侧后->前，两侧错半周期），任意时刻 5 腿支撑。
# 窗序 R3→L1→R2→L3→R1→L2（窗头时刻 = (duty-offset) mod 1 升序）：相邻
# 抬腿全在对角/交叉位（最小间距 167mm），不再同侧三连（旧序 L 三连再 R 三连
# ——半周期扰动集中一侧，08-19 实测 R2/R3 抬腿下坠的结构性根源）也不同排
# 背靠背；同排搭档抬腿间隔恒半周期——前排（上墙剥离力矩集中处）抬其一时
# 另一只已坐实 3 个窗。地面 WAVE 保持原序不动
CLIMB = Gait("climb", 5 / 6, {"R3": 5 / 6, "L1": 4 / 6, "R2": 3 / 6,
                              "L3": 2 / 6, "R1": 1 / 6, "L2": 0.0})
# 双足爬墙步态（docs/DUAL-SWING-DESIGN.md）：偏移与 CLIMB 完全同集，只把
# 占空 5/6→4/6——摆动窗从 1 槽变 2 槽、窗口两两重叠，任意时刻恰 2 腿在窗、
# 稳态恒 4 足吸附。ClimbEngine 的事件驱动钟把窗头攒成"错峰双摆"（对内
# 窗头差 T/6，周期=3×单窗时长）；duty 变小使窗头序整体平移一槽（首腿
# R3→L1），环序不变，仍是对角交替波浪——同刻在空的两腿由"相邻抬腿全在
# 对角/交叉位"性质保证必异侧、必不同排（前排恒 ≥1 只吸附扛剥离力矩，
# 两只最软的中腿永不同时离墙）
CLIMB_DUAL = Gait("climb-dual", 4 / 6, dict(CLIMB.offsets))


def _smoothstep(s: float) -> float:
    return s * s * (3 - 2 * s)


def default_feet(cfg: RobotConfig) -> dict:
    """默认站位的足端位置（身体系，z 相对髋轴平面）。"""
    feet = {}
    for leg in cfg.legs:
        a = math.radians(leg.mount_angle_deg)
        feet[leg.name] = (
            leg.mount_x + cfg.foot_reach * math.cos(a),
            leg.mount_y + cfg.foot_reach * math.sin(a),
            -cfg.stand_height,
        )
    return feet


class GaitEngine:
    def __init__(self, cfg: RobotConfig, gait: Gait = TRIPOD):
        self.cfg = cfg
        self.gait = gait
        self.default_feet = default_feet(cfg)

    def _stride(self, leg_name: str, vx: float, vy: float, wz: float):
        """该腿在一个支撑相内的位移向量（身体系，mm）。
        vx/vy: 身体速度 mm/s；wz: 转向角速度 rad/s。"""
        T_st = self.cfg.cycle_time * self.gait.duty
        px, py, _ = self.default_feet[leg_name]
        # 刚体速度场：v + w x r
        ux = (vx - wz * py) * T_st
        uy = (vy + wz * px) * T_st
        # 限幅到最大步幅
        mag = math.hypot(ux, uy)
        if mag > self.cfg.max_step:
            ux, uy = ux * self.cfg.max_step / mag, uy * self.cfg.max_step / mag
        return ux, uy

    def phase(self, leg_name: str, t: float) -> float:
        return (t / self.cfg.cycle_time + self.gait.offsets[leg_name]) % 1.0

    def stance_legs(self, t: float):
        return [n for n in LEG_NAMES if self.phase(n, t) < self.gait.duty]

    def foot_targets(self, t: float, vx: float = 0.0, vy: float = 0.0,
                     wz: float = 0.0) -> dict:
        """t 时刻各腿足端目标（身体系）。静止指令时全部回默认站位。"""
        targets = {}
        if vx:      # 跑偏补偿：与前进速度成正比，反号抵消实测漂移
            wz -= math.radians(self.cfg.yaw_trim_deg_per_m) * vx / 1000.0
            vy -= self.cfg.side_trim_mm_per_m * vx / 1000.0
        moving = abs(vx) > 1e-6 or abs(vy) > 1e-6 or abs(wz) > 1e-6
        for name in LEG_NAMES:
            x0, y0, z0 = self.default_feet[name]
            if not moving:
                targets[name] = (x0, y0, z0)
                continue
            ux, uy = self._stride(name, vx, vy, wz)
            p = self.phase(name, t)
            if p < self.gait.duty:               # 支撑：+u/2 -> -u/2
                s = p / self.gait.duty
                targets[name] = (x0 + ux * (0.5 - s), y0 + uy * (0.5 - s), z0)
            else:                                # 摆动：-u/2 -> +u/2，抬高
                s = (p - self.gait.duty) / (1 - self.gait.duty)
                ss = _smoothstep(s)
                targets[name] = (
                    x0 + ux * (ss - 0.5),
                    y0 + uy * (ss - 0.5),
                    z0 + self.cfg.step_height * math.sin(math.pi * s),
                )
        return targets


class MarchEngine:
    """原地踏步（手动逐脚）：身体不动，六只脚各是一个开关——按一下抬起，再按踩下。

    进这个状态机器人只保持默认站位不动，抬哪只脚、抬多久全由人按键决定：
    看抬腿幅度够不够、脚有没有被被动真空吸住、单腿悬空时身体沉多少、吸盘
    离地那一下有没有被拽——都可以停在任意一只脚抬着的状态慢慢看。
    足端只动 z、x/y 恒在默认站位（身体不前进不转向）；抬落走 smoothstep
    （两端速度为零，不甩腿），抬到一半再按会平滑折返，不跳变。
    抬起高度 lift_mm 默认 70mm，比步行的 step_height=40 高一截（femur 抬到
    接近竖直）；再高就要当心 femur 过竖直撞身体，改 lift_mm 前先架空试。

    按键布局照机器人俯视：左列 t/g/b = 左前/左中/左后，右列 y/h/n = 右前/右中/右后。
    """
    LIFT_MM = 70.0      # 默认抬起高度 mm（步行 step_height=40，这里"抬高一些"）
    MOVE_S = 0.5        # 单只脚抬起/落下的运动时长 s
    # 键 -> 腿：t y / g h / b n 在键盘上就是一个 2×3 块，跟六条腿的俯视位置对上
    KEYMAP = (("t", "L1"), ("g", "L2"), ("b", "L3"),
              ("y", "R1"), ("h", "R2"), ("n", "R3"))

    def __init__(self, cfg: RobotConfig, lift_mm: float = None, move_s: float = None):
        self.cfg = cfg
        self.lift_mm = self.LIFT_MM if lift_mm is None else float(lift_mm)
        self.move_s = max(1e-3, self.MOVE_S if move_s is None else float(move_s))
        self.default_feet = default_feet(cfg)
        self.keymap = dict(self.KEYMAP)
        self.up = {n: False for n in LEG_NAMES}     # 目标态：True=抬起
        self._s = {n: 0.0 for n in LEG_NAMES}       # 抬落进度 0..1（当前实际位置）

    def leg_of_key(self, key) -> str:
        """按键 -> 腿名（大小写都认）；不是六个踏步键返回 None。"""
        return self.keymap.get(key.lower()) if key else None

    def toggle(self, leg: str) -> bool:
        """切换一只脚：抬起<->踩下，返回切换后的目标态（True=抬起）。"""
        self.up[leg] = not self.up[leg]
        return self.up[leg]

    def update(self, dt: float) -> None:
        """推进一拍：各脚按 lift_mm/move_s 的速度朝各自目标走。"""
        for name in LEG_NAMES:
            goal = 1.0 if self.up[name] else 0.0
            s = self._s[name]
            step = dt / self.move_s
            self._s[name] = min(goal, s + step) if goal > s else max(goal, s - step)

    def height_of(self, leg: str) -> float:
        """该脚当前离默认站位的高度 mm。"""
        return self.lift_mm * _smoothstep(self._s[leg])

    def foot_targets(self) -> dict:
        """当前各腿足端目标（身体系）。"""
        targets = {}
        for name, (x, y, z) in self.default_feet.items():
            targets[name] = (x, y, z + self.height_of(name))
        return targets

    def up_legs(self) -> tuple:
        """目标态为抬起的腿（按 L1..R3 固定顺序）。"""
        return tuple(n for n in LEG_NAMES if self.up[n])

    @property
    def settled(self) -> bool:
        """六只脚都走到各自目标位（没有正在抬/落的）。"""
        return all(self._s[n] == (1.0 if self.up[n] else 0.0) for n in LEG_NAMES)

    def key_hint(self) -> str:
        return "  ".join(f"{k}={n}" for k, n in self.KEYMAP)

    def state_text(self) -> str:
        up = self.up_legs()
        if not up:
            return "六脚着地" if self.settled else "落下中"
        return f"抬 {'/'.join(up)}" + ("" if self.settled else " …")

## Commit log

2026-07-07 初始提交：爬墙六足蜘蛛机器人 DIY 项目
    - docs/: 路线图（风险前置，P2 单腿上墙决策门）、分批采购 BOM、
    爬墙方案论证（吸附选型、力学预算、活动度分析、四足/六足权衡）
    - hardware/makeyourpet-hexapod/: MakeYourPet 六足全套 STL/STEP（MIT，vendored，
    上游 https://github.com/MakeYourPet/hexapod）
    - hardware/climbing-parts/: 自制吸盘足模块与阀组安装板 STL
    - software/: Pi 5 控制包——单腿 IK/FK、三角/波浪/爬墙步态、Servo2040 chica
    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
    [battery-bar.stl, bottom-cover-flat.step, bottom-cover-flat.stl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]
2026-07-07 P0 阶段逐步操作指南 + 重量记录模板
    - docs/P0-GUIDE.md: 下单核对表（含卖家确认要点）、Pi 5 环境搭建命令、
    打印清单（左前腿 L1 + 官方标定工具）、固件烧录、单腿装配顺序、
    摆动测试脚本、验收核对表与常见问题排查
    - docs/weight-log.md: 分阶段称重记录模板（2.5kg 硬上限）
    - ROADMAP/README 挂链
2026-07-10 P0 指南:修正第 4 步电压读数说明,补充割断电源跳线的安全警告
    Servo2040 出厂默认 USB 5V 与舵机供电轨连通,仅接 USB 时读数约 5V
    而非接近 0;接 2S 电池前必须先割断背面跳线,否则会倒灌烧毁 Pi。
2026-07-11 P0 指南:第 5 步新增接电池前强制检查,防电源跳线倒灌烧板
    实际事故教训:跳线未割断 + USB 连着 Pi 时接 2S 电池,电池电压经
    共用供电轨倒灌,烧毁 Servo2040 并危及 Pi 的 USB 口。
    - 第 5 步新增强制检查:割断跳线 → 读电压≈0 验证 → 万用表核对极性
    - 验收核对表补充跳线与极性确认项
    - 常见问题表新增冒烟/无响应的排查处置
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2026-07-13 feat(p1): implement full adhesion state machine and fail-safe hardware logic
    - Updated CLIMBING-DESIGN.md to document the fail-safe plumbing discovery (pump on port 3).
    - Implemented Pi5VacuumIO in software/hexapod/adhesion.py with tested hardware constants (V_ATM = 4.486, VALVE_ON_LEVEL = 0).
    - Created software/test_adhesion_real.py to test the closed-loop suction controller.
    [adhesion.py, test_adhesion_real.py]
2026-07-13 test(p1): enhance adhesion test script with real-time pressure printing and proper hysteresis loop
2026-07-13 feat(climbing): suction_foot v2 适配实购吸盘+直角宝塔一体件
    按实测颈部轮廓（Ø17x5 / Ø15x1.5 凹槽 / Ø17x2，卡持高 8.5mm）重做
    吸盘足：侧滑入卡槽块（内环凸筋锁凹槽 + 入口防脱凸点），C 型护筒
    正面开窗容纳金具并出气管，顶部方轴套筒不变。
    [suction_foot.stl]
2026-07-13 feat(climbing): 按实测金属件总高 36mm 压缩吸盘足腔体，总高 84→73mm
    腔顶参数由估算的 neck_to_elbow=35+10 余量改为实测 fitting_top=36
    （波纹肩部到金属件最高点）+3mm 净空。
    [suction_foot.stl]
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2026-07-13 test(p1): add 60-second vacuum leak rate test script
    [test_leak_rate.py]
2026-07-15 feat(climbing): 吸盘足 v3——与 left-tibia 一体化 + 全形状负模腔体 + 胶粘门盖
    v2 卡槽只夹持硅胶颈部 8.5mm，金具悬臂晃动且硅胶粘不住胶水。v3 按
    三视图实测尺寸把吸盘顶部+双六角螺母+直角宝塔整体做成负模腔体：
    Ø27 折痕锥 / Ø15x1.7 凹槽凸筋 / 边长7、边长5 六角袋锁转动 / Ø9.6
    弯头腔顶到金属最高点。前下方门盖含前半负模+4 定位销，502 粘接；
    门顶以上开放，宝塔嘴可转动出管。腔体经 45° 斜顶与加粗颈柱直接
    并入 tibia 本体（方轴残段埋入颈柱），腿长较 v2 方案缩短约 59mm。
    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
    [left-tibia-suction.stl, suction-foot-door.stl, suction_foot.stl]
2026-07-15 fix(climbing): 腔体下段按实物改为 Ø27 浅座圈 + 5° 肩面 + Ø17 圆柱主孔
    吸盘折痕以上不是整段锥面：只有 5° 的平缓肩部（升高约 0.44mm），随即
    转入 Ø17 圆柱（高约 9.56mm，见 images/xipan_neicao.jpg 手绘）。原大锥腔
    会让圆柱段悬空。现改为 Ø27.6x0.9 座圈 → 5° 让位面（留 0.5 间隙，立打
    桥接微塌无害）→ Ø17.4 主孔（约 7.9mm，真正的侧向夹持段）；参数 cone_h
    改为 shoulder_deg + neck_h，圆柱高度由脚本推算。
    [left-tibia-suction.stl, suction-foot-door.stl]
2026-07-17 docs: finalize P1 physical limits (1.5kg shear, 15 deg angle) and close P1 checklist
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2026-07-17 feat(calib): apply L1 tibia triangle measurement (theta 86.4, tibia_len 120)
    三边实测 FK=80/KP=120/FP=140 → theta_center=86.4°：
    - config: L1 tibia attach_deg 68→93.6（k 基准），tibia_len 134→120（唇口自由态口径）
    - workspace_analysis: THETA_LIM 按实测 attach 重算为 (0, 176.4)
    - 重算行走包络（最紧余量 42°，舵盘不拆结论维持）与 CLIMBING-DESIGN §6 数表
    - 新增 docs/LEG-GEOMETRY-OPEN.md 记录单腿几何排查全程（§2.11 为本次实测）
2026-07-17 feat(calib): apply L1 femur measurement (alpha 49.7); defer coxa to P3
    - femur 高差法实测 Δh=61/FK=80 → α_center=49.7°（=官方35+一齿14.4，落网格自洽）
    - config: L1 femur attach_deg 35→49.7；workspace_analysis: ALPHA_LIM=(-40.3,139.7)
    - 重算：行走包络余量仍充足；地-墙过渡平身 D=100 由不可行变为可行（上抬行程+14.4°）
    - coxa attach 决定推迟到 P3 装机身时用 L1↔R1 基线法测（P0 无机身，γ 零点不存在；
    P1/P2 台架不依赖 γ 绝对值），LEG-GEOMETRY-OPEN §2.12/§5 已记录
2026-07-18 docs(calib): h_cup 三态测齐，l3 收口为两态常数模型
    - §4.4：自由 21 / 压密封 7.5 / 真空(-40~-50kPa) 8（mm）；预压行程 13.5mm
    - 真空态≈密封态 → 波纹在工作区间已压实，支撑相 l3 对真空度不敏感
    - 两态模型定稿：自由 l3=120（摆动/地面）、吸附 l3≈108（P4 支撑相 IK，
    注意 ~2.7° 方向偏转项）；§2.10 标注实测收口
    - 遗留：h_cup=21 与 KP=120 的 4.6mm 张力，P3 FK 抽查裁决
2026-07-18 feat(p2): P2 单腿爬墙指南 + single_leg_wall.py 循环脚本
    - docs/P2-GUIDE.md：台架几何（髋-玻璃 90mm，修正 ROADMAP 的 130 粗值）、
    滑车承力机构、六级分级上量、50 循环决策门验收，仿 P0/P1 指南格式
    - scripts/single_leg_wall.py：单腿 IK + 吸附状态机联调，失败抬 5mm 重试×3，
    CSV 记录压力/电流；Ctrl-C 冻结不放气（防滑车坠落），--release 善后；
    泵按需补抽绕开 P1 单传感器滞环失准
    - 几何用实测标定验证：循环内吸盘轴偏法线 ≤7.5°，压紧位 0.2°，行程余量 ≥40°；
    压紧深度 15mm = §4.4 实测预压 13.5 + 预载 1.5
    - ROADMAP P2 节添加指南链接
    Co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
    [single_leg_wall.py]
2026-07-19 fix(kinematics-model): 吸盘轴 = a_t - 22.7°，修正全部下游（δ 修正）
    膝轴 K(47.8,-14.6) 不在方轴(x=1.3)上 → K→P 虚拟线与真实吸盘轴恒差
    δ=22.7°。此前所有分析拿 a_t 当吸盘轴（§3.1 旧错误的未清理下游）。
    符号旁证：官方地面站姿代入 → 吸盘轴离垂直 9.7°，近乎平贴地面。
    - workspace_analysis.py: 加 CUP_DELTA=-22.7 重算 A/B 两表
    - 墙面支撑相 reach 130→170（旧姿态偏角 16.7° 超容差会吸不住）；
    站高 90 + reach 170 + 步幅 ≤40 → 偏角 ≤11.5°
    - single_leg_wall.py / P2-GUIDE: FOOT_X 122→169（压紧位吸盘轴⊥玻璃，
    全循环偏法线 ≤4.5°）
    - CLIMBING-DESI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
    [single_leg_wall.py, workspace_analysis.py]
2026-07-19 feat(climbing-parts): 新吸盘件适配——45° 肩面、六角 7.3/6、舵盘孔 M3
    - 圆台凹槽母线角 5°→45°；Ø17 主圆柱高改 5mm（neck_h 总高仍 10）
    - 座圈高度与肩部锥面解耦（原 lip_h=rise+0.5 在 45° 下轮廓自交），加 assert
    - 六角袋边长 7→7.3、5→6；45° 锥面立打自承，免环形桥接
    - 舵盘 4 孔 Ø1.69(M1.6)→Ø2.8(M3 自攻)，horn_hole_d 参数化，Ø3.0 让位段保留
    [left-tibia-suction.stl, suction-foot-door.stl]
2026-07-19 feat(climbing-parts): 门盖改 2×M5 螺丝固定，可拆换吸盘
    - 两侧各一颗，孔心 ±10.5mm / z_rel=19（六角袋2 最窄段，避开定位销与外壁）
    - 门盖：Ø5.5 过孔 + Ø9.0×5.5 沉头孔（M5 杯头沉入 0.5）
    - 主体：Ø4.5 自攻底孔，贴合面钻入 14mm 盲孔，M5 咬 PETG（建议 M5×20~25）
    - 定位销保留负责对位，胶粘改为可选
    [left-tibia-suction.stl, suction-foot-door.stl]
2026-07-19 feat(climbing-parts): 试验版 *-exp——折痕面下加 Ø33×7.2 触地环
    - 真空态波纹段缩进空槽，打印件圈直接触地，硬限位分担腿部载荷
    - 环段外廓加宽 38×38 围裙保 2.5 壁，上方外壳保持 34 不变
    - 围裙前半在门上（保住吸盘横向滑入的装配流程），门随之向下加长 7.2
    - 试验版门盖须立打（围裙凸出 2mm，外面不再是整平面）；原版门仍平躺
    - 参数化 pocket_d/pocket_h（=0 即原版），原版两 STL 字节未变
    [left-tibia-suction-exp.stl, suction-foot-door-exp.stl]
2026-07-19 fix(config): L1 tibia 方向反转——换新吸盘件后 ±45 脉宽对调
    换新吸盘件(cdfb4d0 重做舵盘孔)后 tibia 关节物理方向与标定相反：
    发 k=71.5 膝盖收拢、FP 缩至 116mm(方向正确应张开至 ≈164mm)。
    手持爬墙试验中该误差被手补偿了约 44° 根部旋转才吸上。
    对调 us_m45/us_p45 修正；attach_deg=93.6 经 FP 反推偏差 ≤2° 保留。
    [config.py]
2026-07-19 docs: 新增 html/ 存放图解，P2 台架图与 θ 测量图迁入
    图解 HTML 从会话临时目录迁到仓库内长期保存；
    P2-GUIDE 的台架图引用改为 html/p2-rig-diagram.html。
2026-07-19 fix(config): L1 tibia 零位复测 93.6 → 89.3（新吸盘件三边法）
    方向修正(23bde42)后复核零位：回中 FP=145mm → θ_center=90.7°，
    k 零位=89.3；与发 k=71.5 实测 FP=168 反推的 89.35 互相印证。
    P2-GUIDE 前置核对同步更新，并新增规矩：换结构件/重装舵盘后
    标定作废重做。
    [config.py]
2026-07-19 docs(html): FKP 三角与玻璃相对位置图——抬离位 vs 压紧位
    两图同比例：抬离位（z=-70，唇口离玻璃 20mm，吸盘轴偏法线 4.5°，
    FP≈144）与压紧位（z=-105，吸盘轴⊥玻璃，FP≈164=实测值，目标点
    越玻璃 15mm=波纹压缩量）。直观展示 C/F 不动、姿态由三角形变形
    保证，以及 K→P 与吸盘轴恒差 δ=22.7°。
2026-07-19 docs(html): coxa 面板式支座设计图（带立柱）
    滑车板安装的两个实物问题（见 images/suck_wall.jpg）：femur 舵机
    及膝部包络向后突出、coxa 壳体无法"指向"玻璃。方案：面板式安装
    +立柱空腔——壳体藏腔内、轴穿面板⊥玻璃；腔深 51 按回中膝包络
    （61-D22+余量12）留，装台后跑回中安全；面板足侧收短 22，femur
    尾部从缘外通过。打印前实测 D 与 femur 尾距再定稿。
2026-07-19 feat(climbing-parts): coxa 面板式支座 STL——P2 台架滑车板安装
    generate_climbing_parts.py 新增 coxa_pedestal()（参数 ped_*）：
    面板开 40.7×20.6 孔+4×M3 底孔（孔距 49.5×10），腔深 45 按回中
    膝包络留，面板足侧收短 22 让 femur 尾，侧底法兰 4×M4 长槽
    （径向±5.5 可调）+45° 三角肋。84×62×51mm，watertight，
    截面核验通过。面板朝下平躺打印无支撑。
    设计图 html/coxa-pedestal-mount.html 增补 STL 渲染与打印要点。
    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
    [coxa-pedestal.stl]
2026-07-19 feat(climbing-parts): 滑车一体件 STL——支座+滑车板合并锁三节滑轨内节
    generate_climbing_parts.py 新增 carriage_pedestal()（参数 car_*）：
    内节即滑车，用其孔簇固定（M5 圆孔基准+竖/横 M4 槽吸公差，
    螺丝从滑轨侧拧进腔底六角螺母袋）；背面 22mm 凸台只贴内节面；
    上下配重绑扎 M5 网格 ×12 + Ø8.5 锁销耳 ×2；塔体与 coxa-pedestal
    一致。94×122×61mm，watertight，截面核验通过。板背朝下打印，
    腔顶需腔内支撑。
    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
    [carriage-pedestal.stl]
2026-07-19 fix(climbing-parts): 支座/滑车件按 2026-07-19 实测定稿
    实测推翻两处早期估计：X1=-10（femur 轴在壳顶面后 10mm，非前方
    22）、X3=23（femur 组件距 coxa 轴）。据此修订：
    - 腔深 45→38：依据改为壳体深度（实测法兰→壳底 28）+走线 10；
    膝向后包络在径向 84+ 越过板缘 50，与腔深无关，回中仍安全
    - 面板/侧墙足侧 22→18（留 5mm），足侧法兰孔背面 Ø7×6 凸台补强
    - 滑轨孔心距按卡尺实测 10/13（原折算 9.5/16），截面复核精确落位
    两 STL 重生成（84×58×44 / 94×122×54），设计图页面挂实测更正。
    [carriage-pedestal.stl, coxa-pedestal.stl]
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2026-07-21 fix(p2): 保持期最差压力中值滤波，抗单传感器毛刺
    worst/泵补抽改用中值滤波(窗口3)后的压力，P1 单传感器的单样本毛刺
    不再把「保持期最差」带偏(实测 hold 稳在 -68~-69 却报 -57.2)；跳过入 hold
    头 0.5s 稳定期。tick() 返回读到的 kpa，保持期复用同一次读数(worst/补抽/CSV
    一致、worst 可从 CSV 复核)，省掉每步重复读传感器。
    [single_leg_wall.py]
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2026-07-22 docs(p2): P2 决策门通过——验收数据归档 + 核对表定稿
    - 50 循环 100%(50/50 零重试)，hold 最差压力 -69.7~-71.3 kPa
    - 1.5kg×300s 悬挂压力全程 [-81,-55]，补抽带 -55/-65 生效无打嗝
    - 1kg 侧拉通过；验收数据摘要与力矩余量结论记入 P2-GUIDE
    - CSV 归档 docs/data/，台架视频归档 images/p2_wall_suck.mp4
    - 打印进度盘点移至 P3 与第二批快递并行
    [p2_1_5_kg_hold300s.csv, p2_50cycles.csv]
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2026-08-02 add p4-bay
    [p4-bay-baseplate-v0.stl, p4-bay-baseplate-v1.stl, p4-bay-cable-comb-v0.stl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]
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2026-08-07 calib_fit.py: 加 recz 高差法——tibia 立尺读高标定，免斜距、免横向修正
    - recz <Δz> [Δh]（仅 tibia）：Δz=膝轴K螺丝心高−唇口圆心高，k = α + asin(Δz/l3)
    - α 三级来源：本场 femur 拟合 → calib_pm45.json 历史 → recz <Δz> <Δh> 现场
    asin(Δh/l2)；用拟合线时回显 α(femur@当前脉宽) 便于核对
    - 防呆：|Δz|>l3 拒收；>0.95·l3 警告接近竖直（正弦变平+分支歧义）
    - 高度测量对横向偏距（唇↔K盘面 27.5）天然免疫；recd 斜距法保留作交叉验证
    - 顺手：--l3 帮助去掉"116/120 之争"过时话（默认 config=123.7）；
    json 路径抽成 CALIB_JSON 常量并 makedirs
    - --mock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
    [calib_fit.py]
2026-08-07 calib_fit.py 审核修正：mock 下 save 不写盘（防干跑污染真实标定）；recd 报错用 config femur_len 替换硬编码 80
    [calib_fit.py]
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2026-08-11 p4_sensor_check.py 修误报：区分"未接"与"空焊盘悬空"，罐压/备用两路不再报错
    实机首测暴露的问题：板图第 8 路只留焊盘、分压电阻没装，AIN3 悬空后靠输入
    漏电流飘到 0.589V（噪声 5.4mV p-p，比其他路大近十倍），被判成"异常低"误报。
    原逻辑默认八路分压都装了，所以只考虑了"装了分压但没插传感器 → 下臂拉到地
    ≈0V"这一种未接形态。
    通道表加"类别"列（tank/foot/spare），classify() 按类别判定：
    - spare 永远判"空位"，说明悬空读数飘是正常的，不计入故障，
    也不进 --live 监视和 --zero 标定
    - tank 未接时提示是储气罐没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
    [p4_sensor_check.py]
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2026-08-11 docs/P4-GUIDE.md 上线，ROADMAP 挂链接
    P4 整机爬墙集成的逐步操作指南：步态引擎从开环相位表改事件驱动（摆动相拆
    LIFT/TRANSFER/DESCEND/PRESS/WAIT/LOAD 六段）、预压行程与两态足端目标、
    Pi5VacuumIO 从 1 足扩 6 足、气路装配验漏、地面玻璃时序总装、斜面递进上墙，
    外加常见问题表和安全条款。
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2026-08-11 P4-GUIDE 第 2 步补：毛刺抑制、瞬断排查、罐压通道坑、传感器自检实测结果
    2026-08-11 分压板+六路足压传感器实机验收暴露的几件事，全部回填第 2 步：
    - 毛刺抑制列为必做项：状态机现在单点读数就翻 ATTACHED，改成连续 N 次满足
    或中值滤波。起因是首测 S7 晃线读数跳、过会儿又不跳——间歇断连在分压点上
    是 1ms 量级但满量程幅度，一次假的深负压就会放行抬腿，五足变四足。
    明确写清软件滤波是第二道防线，不能替代把接触问题修好。
    - 瞬断排查写进流程和常见问题表：--wiggle N 锁定单路 860SPS 边晃线边抓，
    七步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
2026-08-11 P4-GUIDE 更正 S7 误诊：不是接触不良是人体静电耦合，补泵阀装好后的电磁兼容复测
    2026-08-11 实测定案：S7 "碰一下读数就跳"经三步排除，确认是人体静电耦合、
    板级共性，**焊接完全没问题**。原先写进第 2 步的"典型的间歇性接触不良"是
    错的，留着会误导，改写为三步排除法：
    | --wiggle 看方向 | 正负交替 ⇒ 不是断连(真瞬断单向) |
    | --scope 看幅度 | 仅 -2.8kPa ⇒ 不是开路(应冲 -112kPa 满量程) |
    | 拆开电与力 | 只给力无反应、只给电复现 ⇒ 静电 |
    决定性的一步是对照另一路：--scope 2 表现完全相同 = 板级共性。**任何单路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
2026-08-11 p4-pneumatic-electrical 补单泵工况电流预算，更正合轨跌压的失效方向
    P4-BAY-DESIGN 定的 V0 只装一台泵（超支对策），但本页电流预算只算了双泵，
    于是"少一台泵是不是能省一块 XL6009"这个问题在图纸上答不出来。补两张表：
    - 预算表加单泵行：12V 稳态 1.1~1.7A、峰值 ~3.3A、折算电池侧 2.1~3.2A
    - 新增输入侧核算表：升压模块的电流限在**输入侧**，倍率 = 12/(Vin·η)，
    满电 ×1.62 / 标称 ×1.91 / 后半程 ×2.22。单泵合轨在标称电压下稳态输入
    已经 3.2A，贴着 XL6009 芯片的 4A 峰值限；电池后半程 3.8A 直接超，泵启动
    6.3A 必进限流打嗝。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
2026-08-13 p4-pneumatic-electrical 修正 SS34/100nF 串联画法，下拉改 6.2k，信号地一根即可
    三处，都是这两天答疑里问出来的。
    **图 3B 的吸收支路原图画成了串联**（泵「+」→ SS34 → 100nF → 泵「−」），
    和速查表第 19 行、图 1 的文字"并联"自相矛盾。串联是错的：电容隔直流，串在
    续流路径里会被充满然后彻底失效，抑噪那一路也被二极管单向化。唯一正经的
    D+C 串联拓扑是反激的 RCD 钳位，那必须再并一只泄放电阻。改成两条并联支路，
    各自跨在电机两端，图下加"两者并联，均跨电机两端"。
    这个错在实物上"看起来能用"——通电泵照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
2026-08-16 P4 软件线:climb.py 事件驱动爬墙步态(LIFT/TRANSFER/垂直下探/压入/等吸附,相位可暂停+互锁+重试+漏气冻结),adhesion 判据时间窗防毛刺+七路传感器+罐压失效判断,climb_walk/sim_walk 联调入口;审查修复 10 项(SUCK超时回归/罐压预建门/放气超时/ADC突发限流等),35 测试全绿
    [adhesion.py, climb.py, climb_walk.py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]
2026-08-16 爬墙站位修正:压入位物理吸盘轴⊥面(= a_t-25.2°,非 K→唇心垂直),逐腿解站位半径≈176(旧130偏21°超容差),落点带±12°径向裁剪,速度限幅 climb_max_step=40(吸住的脚不能滑,支撑相真实位移≤步幅),37 测试全绿
    [climb.py, climb_walk.py, config.py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]
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2026-08-16 climb_walk 审核修复:按键改 os.read 直读 fd(方向键误触 ESC 放气退出/缓冲卡死主环,实测复现),f 解冻与吸附完成清零速度,TTY 检查前置到上电前,--cycle 校验,--release 放气读数确认+使能预置爬墙站位,罐压预建门改连续计时+解冻复位;Ctrl-C 文案改真话(有腿悬空时进程退出会泄罐压,系统级问题另议)
    [climb.py, climb_walk.py]
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2026-08-17 无罐模式审核修复:首次抽气前盲抽歧管3s(阀全关容积小,免首足独扛大气歧管烧重试),漏气冻结文案点名落地中的嫌疑腿(无罐时支撑足全读共享歧管,先报漏的往往不是真凶),Ctrl-C 罐压警示无罐时不再打印;39 测试全绿
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2026-08-17 climb_walk 退出收尾补线圈断电:本机阀'通电=排气,断电=通罐',排气是维持态——干净退出把 GPIO 拉高放气后就退进程,引脚停在高电平致六线圈持续通电(实机复现);三条退出路径(ESC全流程/暂停处/--release)收尾统一 coils_off 拉低再走,同 p4_mosfet_check 口径;Ctrl-C 注释按'引脚保持最后电平'的实测修正
    [climb_walk.py]
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2026-08-18 上墙原地踏步对策:状态行加"盘差"(最差已吸附盘压,盯 plateau 过不过 -75)+ --sag-comp 下滑补偿。实测每抬一腿整机被拽下一截——载荷 6→5 足重分配的弹性让位(波纹盘横向+舵机让位角)被下一次吸附锁死成棘轮,6 次/周期吃掉整个步幅;补偿在每次抬腿事件的 LIFT+TRANSFER 段(摆动足离面,不横拖压入中的盘)把全部支撑足沿下坡向(头朝上贴墙=-X,随积分航向旋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
    [climb.py, climb_walk.py, config.py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]
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2026-08-18 审核修复(/code-review 15 项:14 实锤全修、1 项驳回留注释)。一、线圈断电保障五缺口:①ESC×2 退出与 --release 序列全程屏蔽 SIGINT——finally 里被 Ctrl-C 打断会跳过 coils_off/drv.close,正在排气的阀停在通电电平(08-17 事故同款终态);coils_off 移进内层 finally,异常也必达。②adhesion 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
    [adhesion.py, climb.py, climb_walk.py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]
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2026-08-19 审核修复(子agent对抗审核 7a02cf8 报 3 项:2 高实锤全修、1 低留注释)。①加深吸附×下滑补偿出 IK 包络(高,审核仿真实锤):支撑保持段停在加深深度(最深 z=-118)后,COMP_TAIL_MAX=40 的平面总账(按名义 z=-103 校验,tail 40 时后腿最紧 d≈201.7/边界 204.7 余 3mm)不再成立——extra=15 + --sag-comp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
    [climb.py, test_climb.py]
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2026-08-19 器件协同打架专项审核修复(2 项:1 实锤+1 缺口)。①'oo' 取机六阀同刻通电(实锤):六足同帧 request_release → 下一次 ctl.update 在同一控制周期把六个阀线圈全部通电,~25W 阶跃正是 08-18 掉电疑似扳机——claim(足间 0.2s)/ESC 退出/--release 全都串行化过,本路径是唯一漏网,且连"停泵垫 0.3s"也没有(泵停与六线圈通电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
    [climb_walk.py]
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2026-08-19 抬腿门槛 lift_gate_kpa=-50（新配置 + --lift-gate CLI，0=关，范围 -65~-35）：08-19 实测 w 模式 R2 刚过 -30 R3 就抬、R2/R3 抬腿整机被拽下坠——互锁只看 ATTACHED（-30 只是密封判据），窗序 L1→…→R3 首尾相接、每腿都在前一腿刚过线的瞬间开抬；起步头几抬支撑还是泡深的旧真空所以 L 侧无感，越到周期后段刚重吸的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
    [climb.py, climb_walk.py, config.py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]
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2026-08-19 吸盘轴垂直度实测修正 cup_tilt_trim_deg + --tilt-trim CLI（0=关，范围 ±8°）：08-19 地面观察——模型解的"垂直站位"上实机吸盘轴仍向外倾、落点往身体收会更垂直，这正是 L3-DISPUTE 'g' 项（CUP_DELTA 下游，P4）挂账的整机标定：标定残差+带载腿链让位+cup_delta 自由态口径与带载姿态的偏差，分不清也不必分，一个总修正角全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
    [climb.py, climb_walk.py, config.py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]
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2026-08-19 gait-to-servo.html 二轮修订：真机口径修正 + 第 2 章重写（用户反馈"走路的本质"一章看不清楚）。①口径修正——LIFT 原错画成"从面上 0 抬 15mm/0.375s"，改为真机账"从压入位 −18 拔出到面上 +15 共 33mm≈0.83s"（(press_delta+lift_clearance)/lift_speed）；相位钟停点随之落在 LIFT 进行 0.3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
2026-08-20 no-tank"严禁上墙"文案全删（用户实测定案：无罐上墙已多次验证气路无问题）。body_lean/climb_walk 的文档头、--no-tank 帮助、启动警告改为事实描述（无储备真空、挽救弱、断电不保真空、地面/上墙均已实测可用）；adhesion.tankless 注释同步。climb_walk 中断退出分支原以"无罐禁止上墙"为由跳过安全绳提示，现不分模式都提示（措辞改"阀/泵终态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
    Claude-Session: https://claude.ai/code/session_011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
    [adhesion.py, body_lean.py, climb_walk.py]
2026-08-20 vent 弹跳棘轮实验量化报告 html/vent-snap-20260820.html + 实验视频入库。08-20 原地踏步实验（零指令逐腿抬落 2 轮，玻璃墙，stand62/trim6/no-tank）视频 NCC 逐帧量化（0.881mm/px 按人工读数 131mm 标定，相机漂移用窗台参照修正<2px，时间轴对活动对比度 off=135.25s）：①每轮下滑 57→74mm，吸盘零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
2026-08-20 docs/HANDOVER-DESIGN.md：vent 前零力交接实现设计（定稿待实现，下个会话照此开工）。依据 08-20 原地踏步量化（83% 下滑在密封破裂瞬间、慢放气被数据否决），机构=窗头决策后插 HANDOVER 相位：被抬腿沿上坡还 δ 卸载、其余支撑腿各沿下坡 δ/5 接载（均值不变=身体不动），铺完才 request_release 进 VENT；δ 逐腿配置（LegConf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
2026-08-21 开发时间线页面 html/dev-timeline-20260821.html：整理 07-21~08-21 共 28 个会话 403 条用户消息，逐日事件+发问时刻+关键原话，六类标签（问题/提问/决定/事故/破局/纠偏），含 22 天总览表、跨天复盘（三次破局皆靠实物实测对质、原地踏步四天因果链、两次疑似硬件报废均虚惊、四次用户纠偏记录）与 A/B 待办
    Claude-Session: https://claude.ai/code/session_01HTetDAG5xSZBJ3jAX9sk3E
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2026-08-23 I2C 总线级失联的 0.5s 容忍+重试（Pi5VacuumIO._kpa）。诱因：08-23 上墙（lean_20260823_165641.log）两次全机冻结"IO 持续失败 [Errno 121] Remote I/O error"，验尸证据链：①三次 121（两次冻结+一次退出期）全部落在泵/阀通电后 0.05~0.6s 内，安静段几百次/秒 I2C 零失败，维持性泵启动 5 次炸 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
    [adhesion.py, test_adhesion.py]
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2026-08-23 零力交接 v1.6 审核加固：引擎侧 7 条确认问题全修 + 启动吸附序改窗序。背景：对 v1/v1.5 三提交（33810d3/5110e46/23ed5fc）多代理审查确认 15 条（引擎 7 + 量化管线 8，管线修复见下一提交），全部对抗验证过、多条实跑复现。共性根因=HANDOVER 相位按 VENT 的待遇写（"正在离场"），实际需要 STANCE 的待遇（密封、承载、且正被系统性加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
    [body_lean.py, climb.py, climb_walk.py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]
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2026-08-24 --leg-order：抬腿窗序可配置（含启动吸附序同步跟随），两脚本同开。用法：--leg-order L1_R1_L2_R2_L3_R3（下划线或逗号分隔、不分大小写，必须六腿不缺不重的排列否则 ap.error 拒绝），启动打印实际生效窗序（打 eng.slot_order 不回显参数=证明相位表真按新序生效）+黑匣子参数行记 leg_order= 便于事后分组。实现=零下游改动的正道：窗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
    [body_lean.py, climb.py, climb_walk.py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]
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2026-08-24 html 报告：零力交接 δ 三组标定（handover-delta-calib-20260824.html，vent-snap 同族样式）。08-24 三组原地 A/B（δ=0/12/24）量化分析入库：主图=逐腿弹跳-δ 散点+线性拟合+外推零弹跳点 δ*（悬停可读，旧上限 25 画参考线）配逐腿汇总表（δ* 38.9/41.4/36.6/27.7/28.0/30.4，轮 3 复核，新表 δ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
2026-08-24 双足爬行（dual-swing）v1：CLIMB_DUAL（duty 5/6→4/6，偏移同集）+ 引擎"一次一腿"多摆泛化 + 两脚本 --dual，设计/协议/管线同步入册。拍板（08-24）：A 形态=duty 改+引擎泛化（错峰双摆自然涌现，弃 3 窗同步对）；B v1 双足禁 --sag-comp/--handover-weights（CLI ap.error+引擎口 ValueErr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
    [body_lean.py, climb.py, climb_walk.py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]
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2026-08-24 双足权重解禁（dual-swing v1.1）：--handover-weights 双足可同开，份额改"按轮转距离取值+当前支撑集就地归一"（_share_now 每 tick 现算），双足专用档 1,1,1,0,0。动因（08-24 用户实测）：双足 δ 30~35 简测仍明显下移，且单足权重上墙实测对下滑改善明显——"晚轮到多接"稀释机理实机成立，拍板 B 权重部分当日修订（sag 禁令不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
    [body_lean.py, climb.py, climb_walk.py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]
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2026-08-26 论文总纲多角度评审调整 + T5 文献细查完成入库 docs/RELATED-WORK.md。PAPER-PLAN 十二处改:①贡献措辞三修——"实验发现"替代"新物理"(发现2是本机特性表征)、量化管线降为方法学支撑不作独立新颖性主张、贡献③收窄(见⑥);②头条数口径问题显式挂出(08-20 踏步 83% vs n=3 A 组 vent 段 93%,摘要只能用一个,T6 统一);③统计设防三件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
2026-08-26 C2 对时修正 + T1 刚度模型拟合完成:交接段分解账翻案(九成是蠕变共模非刚度不均),门控否决原 D 设计、改立 D′ 铺设提速判别实验。①C2(0825pm/C)对时更正:拟合前核对九组分解表发现 C2 逐腿模式物理不可能(大坠在 R2/L2,同日 B2 与 C1/C3 均在 L1/R1)——阶跃救援锁错周期梳齿一格:该组 vent 轮内间距高度周期化(17.5~18.5s),错位一格 R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
2026-08-26 D′ 判别实验实现落地:交接铺设速率参数化 --handover-rate(默认 10 不变,实验档 20),协议新增 §9,单测 113→115 全绿+pty 冒烟过,待上墙。缘起=T1 拟合(html/stiffness-fit-20260826.html,上个提交):交接段 ~九成是"共模下沉≈蠕变率×窗时长",而窗时长≈0.5+δ/rate 与 δ 完全共线——"时间蠕变 vs 逐 mm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
    [body_lean.py, climb.py, climb_walk.py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]
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2026-09-01 kim2008smooth 全文入库+误引修正:paper/references/kim2008smooth.pdf(Stickybot T-RO 2008,MIT 第一作者公开版 10 页,标题/作者与 refs.bib 核对一致)——写作范本首选(叙事弧同构)兼贡献①③划界必引。逐字核引语发现 main.tex Related Work 此前把检索摘要的转述套了引号=误引风险,已改为原句 "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
2026-09-01 论文中文对照版入库:paper/main_zh.tex→main_zh.pdf(8 页,英文 9 页),与 08-31 英文稿逐节对应——摘要至结论/表 I·II/四张实图/式(1)~(5)/45 条引文完全一致仅换语言;图表编号本地化(图/表),\TODO 标记中文化,术语沿用项目既有叫法(vent-snap 棘轮/零力交接/交接段/逐 mm 损耗/传递比/宁欠勿过),kim2008smoot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
2026-09-01 论文事实核查修正(中英文同步,重编译:英 10 页/中 8 页):起因=用户指出摘要"不用任何力/触觉/气压/电流反馈"与机器人实有六路盘压传感器矛盾。①传感措辞:全文 7 处"零传感器/no pressure feedback"改为"交接不用传感反馈/不新增传感/无力传感"(摘要:卸载量来自离线表,吸附时序本就依赖的盘压传感器在交接中不起作用;贡献③ sensor-free→force-sen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
2026-09-02 自听回声过滤:修复实机 --trust-aec 自问自答死循环。起因=09-02 树莓派实机 voice_check 一次通过(卡名 Lite,唤醒/识别/TTS 全对,加载时 Unknown token: shei2 ×4 是 matcha 词典"谁"读音缺 token 无害),但 voice_teleop --mock --trust-aec 暴露两个连锁问题,根源=板载 AEC 没压住喇叭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
    [test_voice_echo.py, voice_check.py]
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2026-09-02 "自我介绍"长回话 + 急停打断说话 + KWS 说话期间常驻:为"机器人说话时喊停下"命中率测试铺路。起因=用户要测说话期间急停命中率,但现有回话全是 1~3s 短句没有测试窗口。新增=intents "自我介绍/介绍一下/你是谁/你叫什么"→kind=intro,回 INTRO_REPLY(≈15s 长介绍;**措辞纪律:不得含 KWS 急停词 停下/停止/停下来/别动**,否则机器人念到那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
    [test_voice_echo.py, voice_teleop.py]
2026-09-02 说话期间急停命中率三杠杆 + 自唤醒尾巴修复 + 声纹锁。第一批(实机命中率第一测=0 后,根源=纯声学掩蔽:KWS 在听——自己念的"小蜘蛛"都抓到了——但用户喊声被喇叭压住,且混进 7.2s 回声段被整段丢弃):①**分句播报**——Speaker 长回话按句切开(split_sentences 保留标点)、句间 0.45s 静音窗(gap_s),AEC 无效时这是 KWS 听清用户喊声的主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
    [test_voice_echo.py, voice_enroll.py, voice_teleop.py]
2026-09-02 模型下载加固:修"Protobuf parsing failed"(树莓派声纹模型文件损坏)。起因=实机 voice_enroll 加载 campplus 模型报 Protobuf parsing failed——下载坏了:setup 脚本的 curl 没加 -f,镜像错误页/断传被原样存成 .onnx。改=①voice_setup.sh 新增 fetch_file(curl -fSL,HTTP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
2026-09-02 急停收尾两修(打断漏一句+失聪看门狗) + 声纹误拒修复(多尺度注册)。第一批(实机命中率第二测:说话期间喊"停下"已命中✓,但暴露两问题):①急停打在"下一句正在合成"的 ~1s 窗口时合成完照样开播(cancel 只查句首;日志证据=tts 合成"你可以让我前进…"出现在急停之后)→Speaker.run 在 render 后、开播前再查一次 _cancel,新增 tests/test_vo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
    [voice_enroll.py]
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2026-09-03 走路时要喊很大声才听见（实机反馈）：唤醒词放灵敏 0.25→#0.20 :1.5 + voice_check --noise-test 三段引导量化归因。定性=物理仗不是 bug：18 舵机长在麦克风旁边磨、用户声音隔一两米，走动时信噪比塌方；嫌疑按大小①舵机噪声+机身振动经安装点直传麦克风板（结构传导比空气声毒）②板载 AGC 被持续噪声压住增益连用户声音一起压小③越走越远。软件侧能给的：①k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
    [voice_check.py]
2026-09-03 amixer 增益杠杆证伪收口：Lite USB 固件不暴露任何混音器控制项，主机侧无录音/放音增益可调。实机证据=scontrols 返回空、controls 只有 Clock Source Validity+两个 Channel Map（时钟有效性只读标志+声道布局描述符，全是管路元数据无一是音量），增益/AGC 全锁在 XU316 片内。改=①voice_check.py --noise-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
    [voice_check.py]
2026-09-03 录音口被占的报错说人话：ArecordSource 遇 "Device or resource busy" 时提示改为"voice_teleop/voice_climb 还开着？残留 arecord？查占用 fuser -v /dev/snd/*、清残留 pkill -f arecord"，其余失败仍提示查声卡/audio 组。起因=实机跑 voice_check --noise-test 直接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
    [voice_check.py]
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2026-09-04 仓库定 MIT 协议 + 上游 MakeYourPet 衍生件补声明 + 论文补两条引用。起因=准备发 YouTube Shorts 挂 GitHub 链接，核对版权：上游 MakeYourPet/hexapod 为 MIT（hardware/makeyourpet-hexapod/LICENSE 原文一直在，硬要求已满足），但①本仓库无 LICENSE，法律默认"保留所有权利"，与开源传播意图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
    [generate_climbing_parts.py]
2026-09-04 README 重写成项目介绍（面向从 YouTube/GitHub 首页进来的读者）+ 封面动图 + 打印件说明独立成文。起因=准备发 Shorts 挂仓库链接，原 README 是"仓库说明"（文档表+打印细节+快速开始），第一屏看不出这台机器做到了什么。改=①README：标题下四个徽章（MIT/Pi 5/Python/零件≈¥2000）+ 封面 GIF；一段话定位（地上走+竖直玻璃爬、几十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
2026-09-05 启动死机根因定案入库：案卷 html/pi-crash-ground-loop-20260904.html + P4-GUIDE/验尸脚本改为定案口径。起因=09-04 晚三条实机证据把 09-02 起的 Pi 5 启动死机（灯绿→红常亮、SSH 失联）钉死：①用户发现每跑一次 walk_teleop 粘滞位必从 0x0 变 0x50000 即使没死——偶发致命事件有了确定的非致命替身，实验判据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
2026-09-06 power_reset 从启动死机证据里撤下：案卷/P4-GUIDE/验尸脚本/软件 README 及英文镜像同步更正。起因=09-06 用户装 ADuM3160 USB 隔离器后做对照：正常 poweroff/reboot 几次之后 /proc/device-tree/chosen/power/power_reset 仍读 00 00 00 02，与 09-03/09-04 两次死机后的读数相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

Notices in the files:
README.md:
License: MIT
